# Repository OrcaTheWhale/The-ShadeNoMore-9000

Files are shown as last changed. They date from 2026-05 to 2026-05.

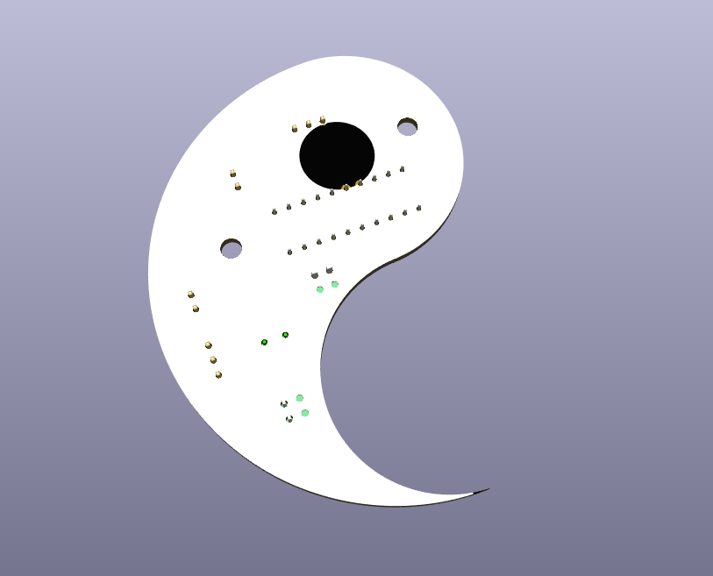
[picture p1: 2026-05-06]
assets/PCBBackSide.png

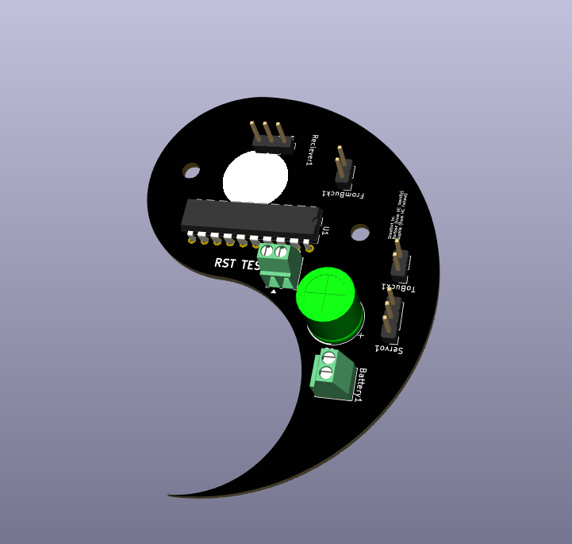
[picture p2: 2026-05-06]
assets/PCBFrontSide.png

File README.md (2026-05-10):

# The ShadeNoMore 9000

The ShdeNoMore 9000 is a product designed to make being lazy look cool. Featuring IR receivers like the ones in TV's, you can close and open your curtains using a remote! It's designed to be a household item, featuring common AA batteries. It's also designed in a way where you can put two halves of a design onto each slider piece, and when the product fully closes, it'll connect together and make the piece whole!

Why I made this project:
I wanted to create a household item using a low power microcontroller, and accessible in the way of replacing batteries. Normal people wouldn't have like 3.7V or 7.4V or the sorts of batteries around them, so the project is designed around AA batteries, which are common.

I also made this project because of one thing: The design connection concept. On the sliders, there is clips where you can put two halves of 3D prints or anything like that, and when the curtain fully closes, it'll make the piece whole through the two sliders. That is why the PCB and the remote is and has a design of a Yin and Yang(The PCB technically won't actually match up if you flip the board, but whatever it looks cool). 



How to use it:

**IMPORTANT: The rightside PCB has the IR Receiver soldered onto the BACKSIDE of the PCB, not the front.**

**Your curtain rod MUST be a circle and have a diameter of 1.5cm with the files/CAD provided. If it is a different value, you may adjust sizes accordingly. If your curtain rod is longer or shorter than usual, you can just change the firmware value or change the linkage length.**

Base: Attach both on the rail. The hole tolerance is meant to be tight so it doens't move. Put servo motor in its cubby first. Then, attach the PCB, and the buck converter. Then, slide the servo right fully, and attach the horn on the _outside_ of the base. Then, screw in the servo mount into its respective hole. Put the battery in its cubby and attach the base cover. Repeat for the other base, but mirror the direction, so that the servo horn faces the other way than the previous.

Attach a base on left side of the curtain rod. Make sure the curtain is **open.** Also make sure the base you're attaching has the hole on the servo side. Then, put the sliders in between the innermost curtain slot and the secondmost curtain slot. If that's not how your curtain works, you may attach a clip instead. 

For the right side, use the other base, the one with the hole on the PCB side.

**Design:**

Your design mounts should look like a "lollipop".
The head should be < 4mmx4mm  (no tolerances included), and the stick should be < 3mm. Max mount length: 2cm / 20mm.

On your designs, the sides closest to each other on each mount should be > 10mm.

Take a look at this example(Units in mm): 



You could make it bigger if you wanted:



**BOM**:

You may find the BOM here: [BOM.csv](https://github.com/OrcaTheWhale/The-ShadeNoMore-9000/blob/main/BOM.csv)

The prices are high for small parts due to the prices include shipping.

*Jumper Wires: Realistically, you SHOULD HAVE jumper wires of such short length, about 24-30 AWG.

The Machine Screws are in a kit because the kit has all the different lengths, and nuts needed. Buying each part individually would only increase unnecessary costs.

PCB:





Schematic:


Remote Schematic:


CAD: https://cad.onshape.com/documents/52cdd38d5fc3852829c5e378/w/375261aaecfc0994e985cde6/e/3bd0b3ebbb21816225754123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

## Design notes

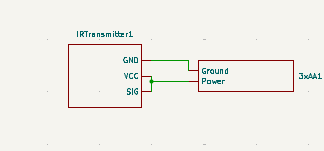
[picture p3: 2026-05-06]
assets/RemoteSchematic.png

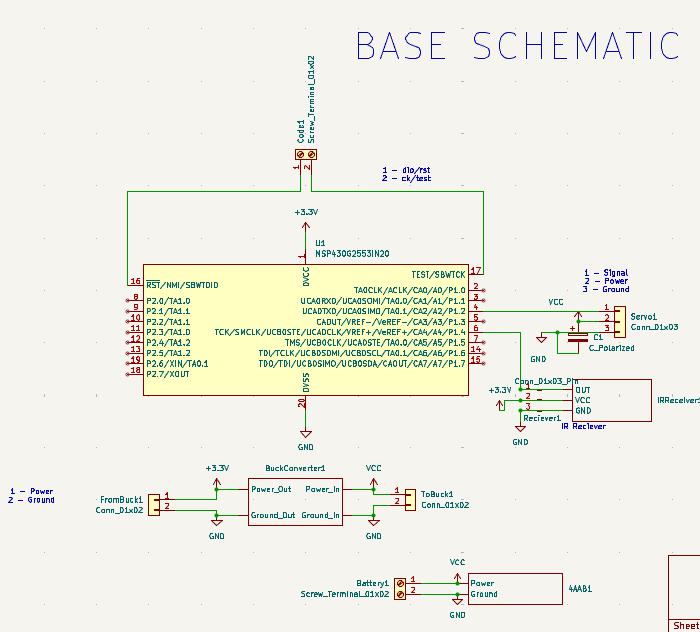
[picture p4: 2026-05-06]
assets/BaseSchematic.png

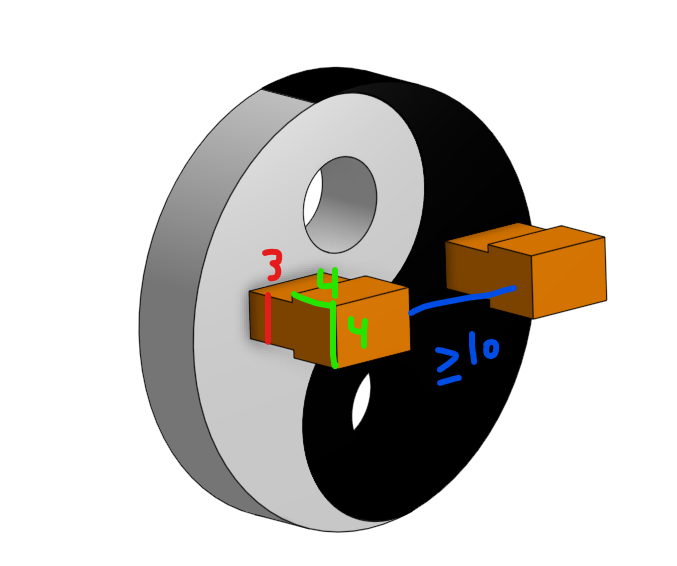
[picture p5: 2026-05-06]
assets/MountExample.png

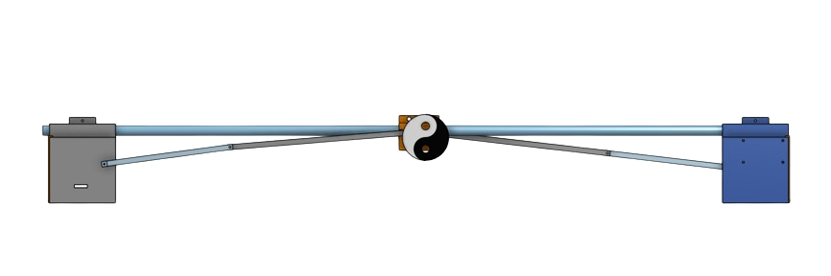
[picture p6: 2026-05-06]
assets/image-removebg-preview (1).png

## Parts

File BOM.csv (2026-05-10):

Component Name | Quanitity | Price | REF | Link
IR Reciever + Transmitter | 1 | $4.53 |  | https://www.aliexpress.com/item/32675916539.html?curPageLogUid=plpMi6Lgedpu
IR Receiver | 1 | $2.88 | Receiver1 | https://www.aliexpress.com/item/1930186275.html?spm=2114.12010108.1000023.2.6HwVeR
Buck Converter | 2 | $9.60 |  | https://www.aliexpress.com/item/1005008071725734.html?curPageLogUid=IOWHT9RBcK8A
MSP430G2553 | 2 | $13.22 | U1 | https://www.aliexpress.com/item/1005008421058049.html?curPageLogUid=ek5zB83Puujk
MSP430G2553 LaunchPad | 1 | $27.44 |  | https://www.aliexpress.com/item/1005007189292097.html?curPageLogUid=2tV5OqEq3V2M
2 Pin Screw Terminal 2.54mm | 2 | $3.46 | Code1, Battery1 | https://www.aliexpress.com/item/1005002549483233.html?curPageLogUid=Ze1MaWzTkJNH
Male Pin Headers 2.54mm | 3 | $7.65 | TuBuck1, FromBuck1 | https://www.aliexpress.com/item/1005006181780843.html?curPageLogUid=kJgwXwCjDtbw
Capacitor 16v 470uF | 1 | $8.28 | C1 | https://www.aliexpress.com/item/1005006192445408.html?curPageLogUid=cPNPzdQAczTI
4x AA Battery Pack | 2 | $9.99 |  | https://www.amazon.ca/LAMPVPATH-Battery-Holder-Switch-Leads/dp/B07L9M6VZK?s=electronics
MG996R (Kit) | 2 | $8.62 |  | https://www.aliexpress.com/item/1005001878275044.html?curPageLogUid=Is8JcX1q9ld8
3x AA Battery Pack | 1 | $3.12 |  | https://www.aliexpress.com/item/32850286281.html?src=google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
M3(OD4mm) Heat Set Insert | 23 | $3.53 |  | https://www.aliexpress.com/item/1005008666672949.html?curPageLogUid=4Nm5SeP7s2is
M3 Machine Screw Kit | 1 | $9.87 |  | https://www.aliexpress.com/item/1005007021342718.html?curPageLogUid=8UvW5TxlCF0z
AA Batteries | 11 | $14.99 |  | https://www.shoppersdrugmart.ca/duracell-copper-black-aa-8-pack/p/BB_041333825014?variantCode=041333825014
*Jumper Wires ~3cm | 8 | $8.41 |  | https://www.aliexpress.com/item/1005008606823974.html?curPageLogUid=bhzxZDESKeOj
CC9000 PCB | 2 | $3.50
PLA Filament |  | 0.5kg
Total |  | $157.17

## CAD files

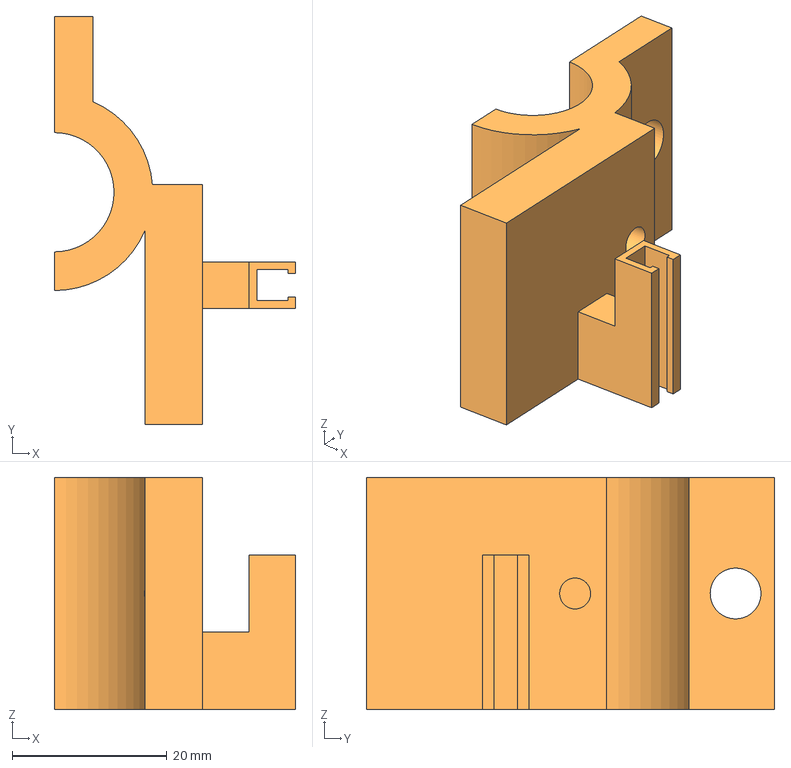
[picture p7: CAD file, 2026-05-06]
StepFiles/CurtainParts/Parts - Part 2.step
31.2 x 52.7 x 30.0 mm

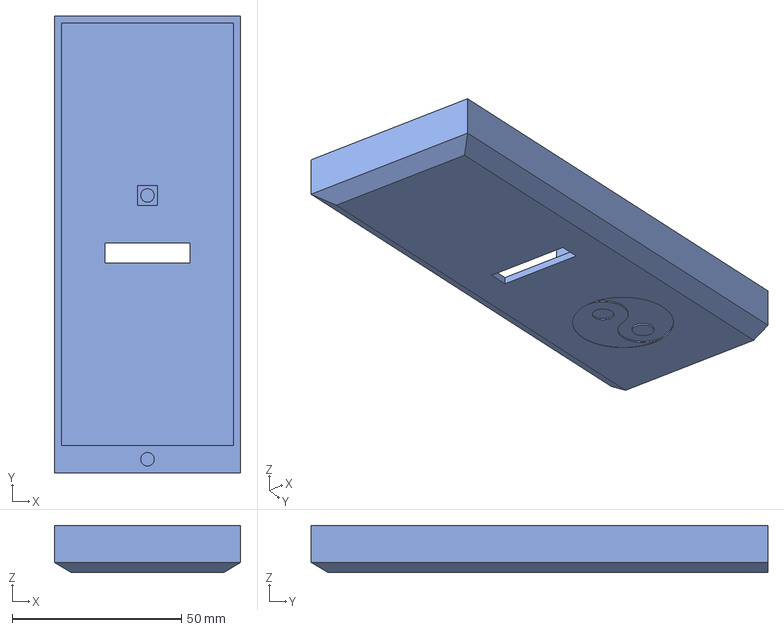
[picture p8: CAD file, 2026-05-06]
StepFiles/RemoteParts/Remote - RemoteTop.step
55.0 x 135.0 x 14.0 mm

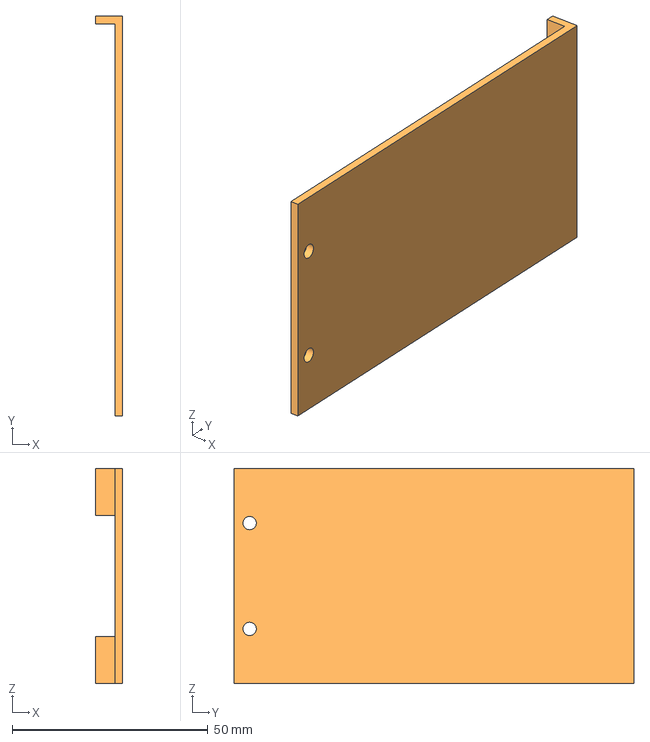
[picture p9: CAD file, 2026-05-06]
StepFiles/CurtainParts/Parts - BaseCase.step
7.00 x 102.1 x 55.0 mm

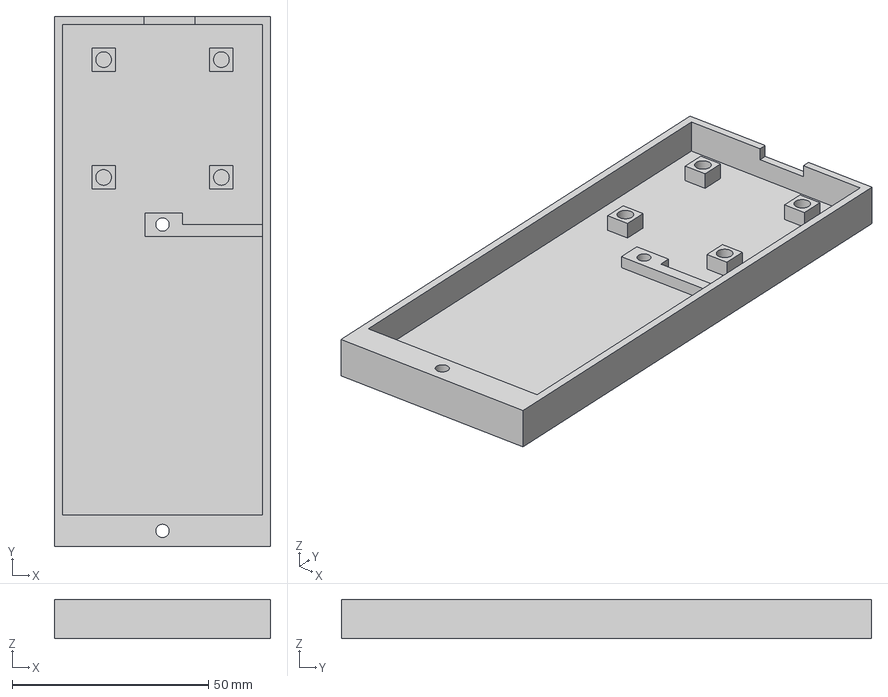
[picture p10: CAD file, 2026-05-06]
StepFiles/RemoteParts/Remote - RemoteBottom.step
55.0 x 135.0 x 10.0 mm

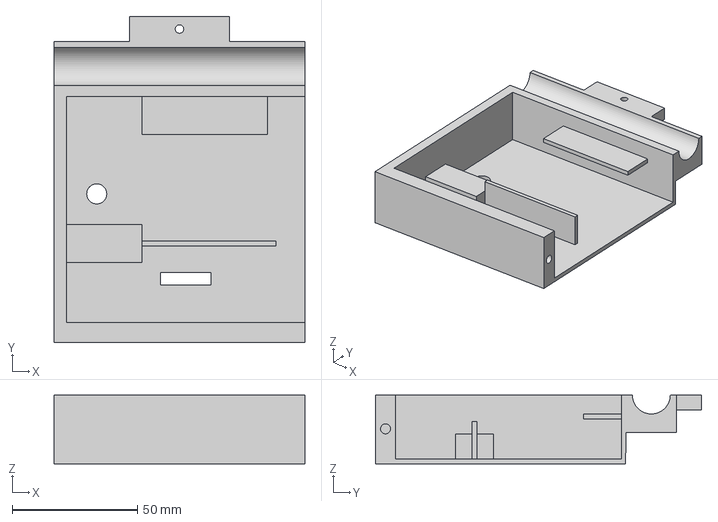
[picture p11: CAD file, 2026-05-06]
StepFiles/CurtainParts/Parts - LSideBase.step
100.0 x 130.0 x 27.5 mm

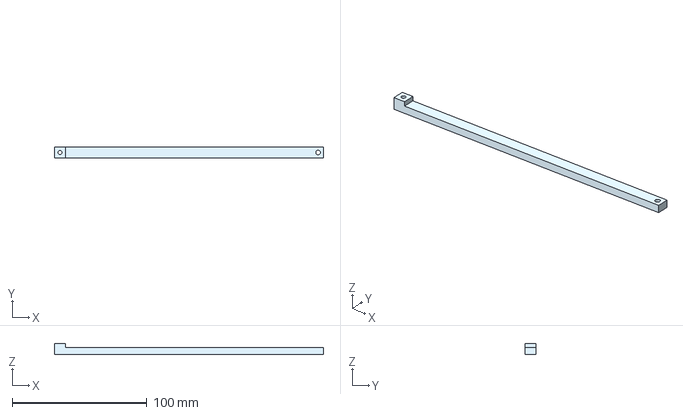
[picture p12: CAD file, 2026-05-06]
StepFiles/CurtainParts/Parts - Link.step
200.0 x 8.00 x 8.00 mm

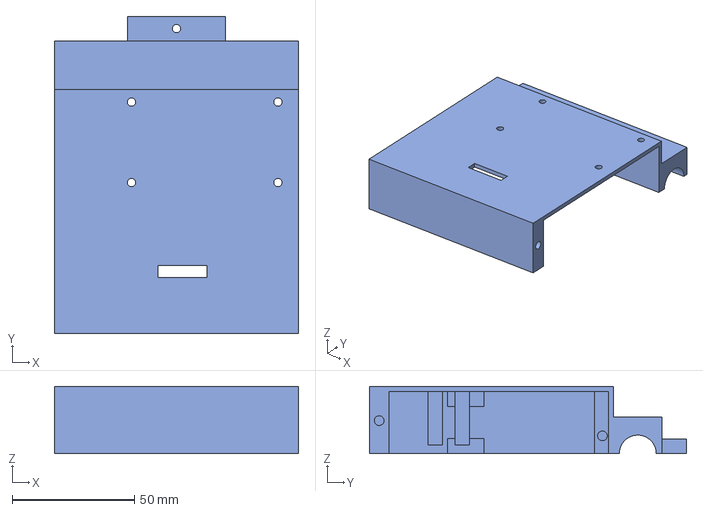
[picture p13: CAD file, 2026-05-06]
StepFiles/CurtainParts/Parts - RSideBase(R).step
100.0 x 130.0 x 27.5 mm

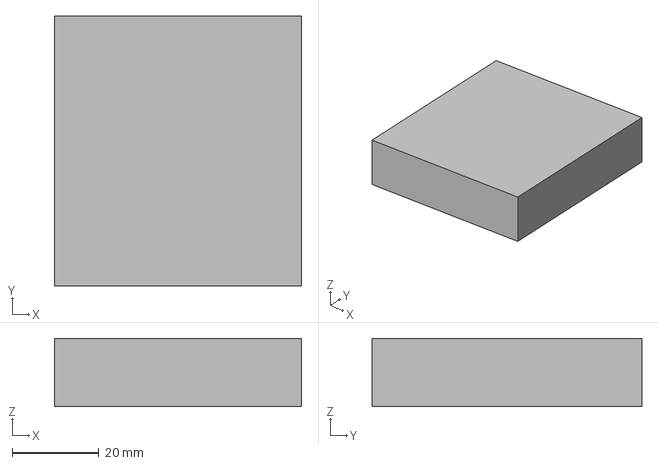
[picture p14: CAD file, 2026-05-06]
StepFiles/CurtainParts/Parts - BatteryCase.step
57.1 x 62.3 x 15.8 mm

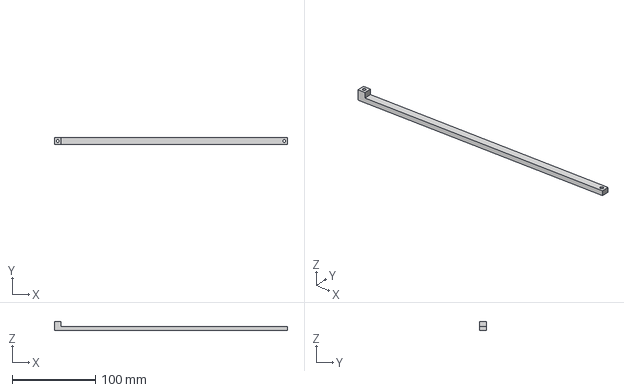
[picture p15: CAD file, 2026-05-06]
StepFiles/CurtainParts/Parts - Linkage.step
280.0 x 8.00 x 10.7 mm

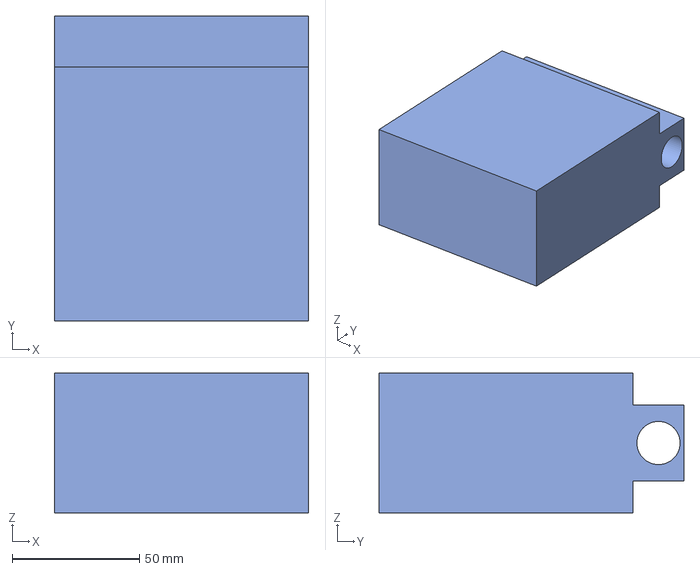
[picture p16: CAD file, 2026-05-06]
StepFiles/CurtainParts/Parts - Stand.step
100.0 x 120.0 x 55.0 mm

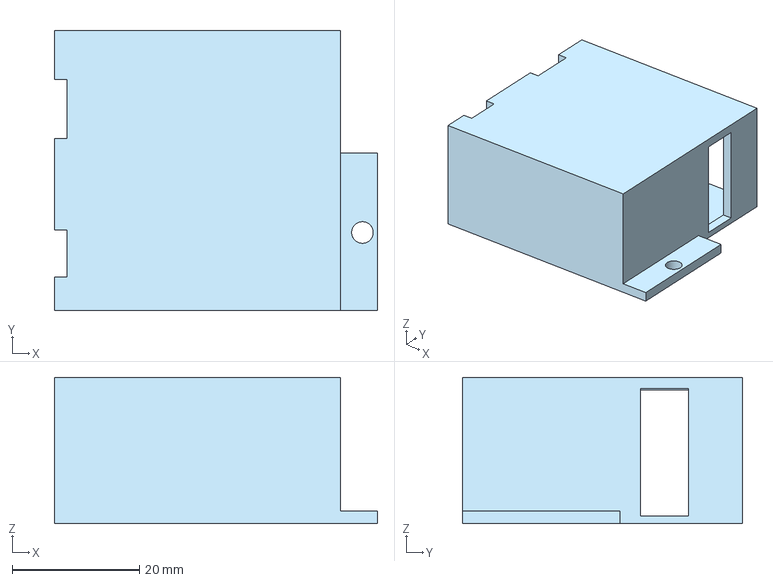
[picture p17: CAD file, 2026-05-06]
StepFiles/CurtainParts/Parts - ServoCase.step
50.8 x 44.0 x 23.0 mm

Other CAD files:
StepFiles/CurtainParts/Parts - RSideBase.step
StepFiles/CurtainParts/Parts - LSideBase(R).step

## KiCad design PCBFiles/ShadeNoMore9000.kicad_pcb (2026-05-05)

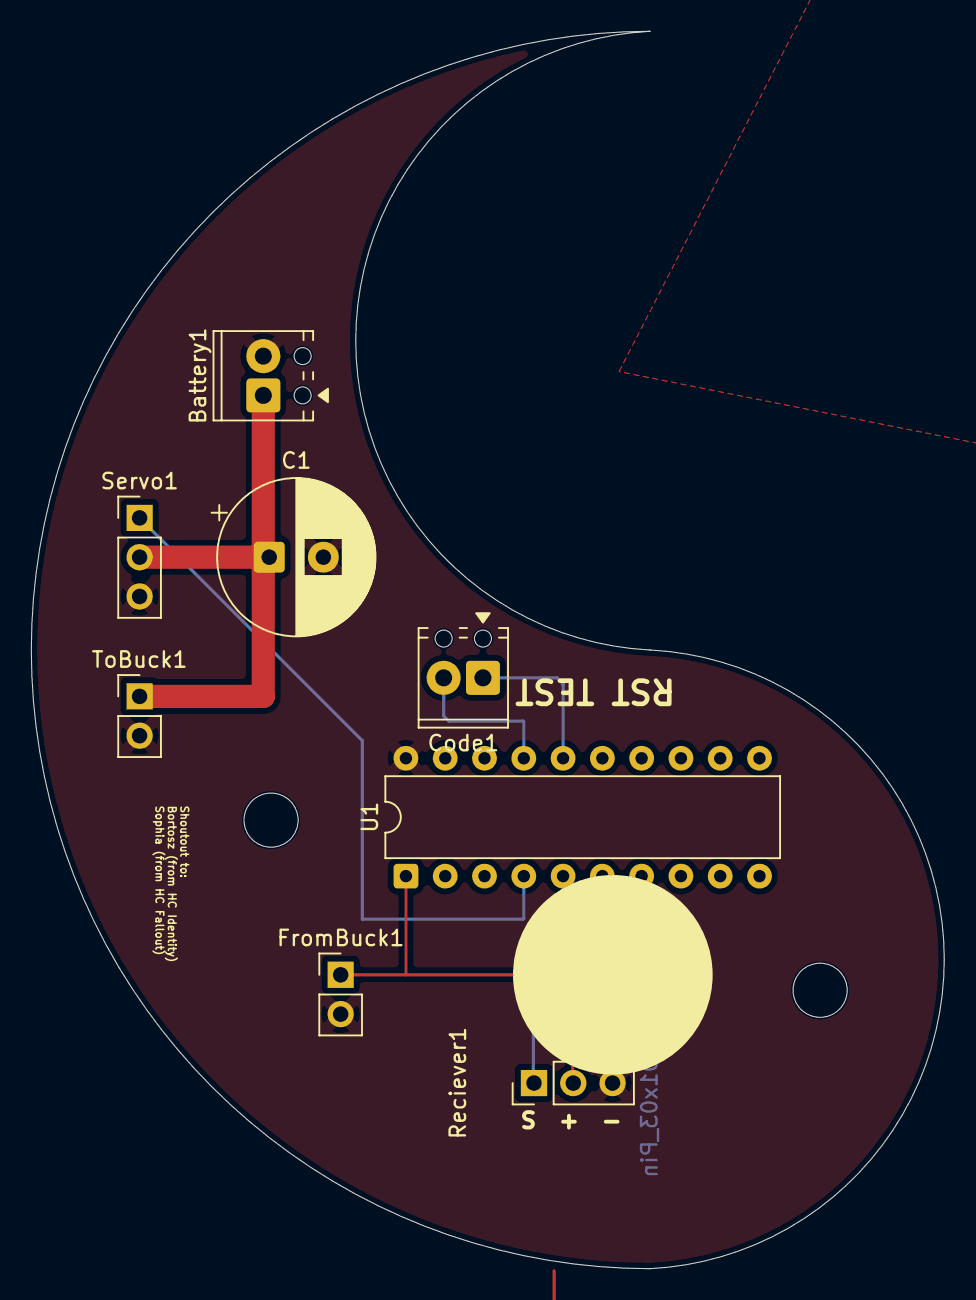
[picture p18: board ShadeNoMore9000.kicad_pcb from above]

Board: 4 copper layers, 59.0 x 80.0 mm, 8 parts (0 on the bottom side), 7 nets.

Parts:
Battery1: Screw_Terminal_01x02; TerminalBlock_Phoenix_MPT-0,5-2-2.54_1x02_P2.54mm_Horizontal
C1: C_Polarized; CP_Radial_D10.0mm_P3.50mm
Code1: Screw_Terminal_01x02; TerminalBlock_Phoenix_MPT-0,5-2-2.54_1x02_P2.54mm_Horizontal
FromBuck1: Conn_01x02; PinHeader_1x02_P2.54mm_Vertical
Reciever1: Conn_01x03_Pin; PinHeader_1x03_P2.54mm_Vertical
Servo1: Conn_01x03; PinHeader_1x03_P2.54mm_Vertical
ToBuck1: Conn_01x02; PinHeader_1x02_P2.54mm_Vertical
U1: MSP430G2553IN20; DIP-20_W7.62mm

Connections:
+3.3V: FromBuck1.1, Reciever1.2, U1.1 (DVCC)
GND: Battery1.2, C1.2, FromBuck1.2, Reciever1.3, Servo1.3, ToBuck1.2, U1.20 (DVSS)
unnamed: Code1.1, U1.16 (~RST/NMI/SBWTDIO)
unnamed: Code1.2, U1.17 (TEST/SBWTCK)
unnamed: Reciever1.1, U1.6 (TCK/SMCLK/UCB0STE/UCA0CLK/VREF+/VeREF+/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)
unnamed: Servo1.1, U1.4 (UCA0TXD/UCA0SIMO/TA0.1/CA2/A2/P1.2)
VCC: Battery1.1, C1.1, Servo1.2, ToBuck1.1

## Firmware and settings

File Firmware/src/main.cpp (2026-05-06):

#include <Arduino.h>
#include <Servo.h>
const int receiverpin = 6;
const int ServoPin = 4;
Servo myServo;

bool closed = true;
bool bounce = false;

int maxangle = 90; // Change to reduce stall

void wake() { // Interrupt function, wakes up the microcontroller
  wakeup();
}

void setup() {
  // put your setup code here, to run once:
  //_bis_SR_register(LPM1_bits); // Sleep mode?
  pinMode(receiverpin, INPUT);
  myServo.attach(ServoPin);
  attachInterrupt(receiverpin, wake, FALLING); // When the receiverpin goes LOW, wake function is called. The IR receiver outputs LOW when it receives a signal.
}

void loop() {
  // put your main code here, to run repeatedly:
  int val = digitalRead(receiverpin);
  if (val == LOW && bounce == false) { // Bounce so it happens only once per time the receiverpin is HIGH
    bounce = true;
    if (closed) {
      for (int i = 0; i < maxangle; i++) { // Move slowly
      myServo.write(i);
      if (val == LOW) { // Cancel the movement if interrupted
        break;
      }
      delay(10);
    }
    closed = false;
    } else if (!closed) {
      for (int i = maxangle; i > 0; i--) { // Move slowly
        myServo.write(i);
        if (val == LOW) { // Cancel the movement if interrupted
          break;
        }
        delay(10);
        closed = true;
      }
    }
    
    
  } else if (val == HIGH) {
    bounce = false;
  }
  suspend(); // Sleep the microcontroller
}

// put function definitions here:
